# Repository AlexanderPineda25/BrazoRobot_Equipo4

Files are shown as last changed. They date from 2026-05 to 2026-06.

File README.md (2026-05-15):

# 🦾 BrazoRobot_Equipo4

**Diseño Colaborativo, Manufactura Remota y Construcción de un Pequeño Brazo Robot de 4 Grados de Libertad**

> Proyecto integrador — Manufactura Aditiva e Industria 4.0 (Electiva Profesional 4)  
> Facultad de Ciencias Básicas e Ingeniería — Universidad de los Llanos, Villavicencio, Meta  
> Mayo 2026 · Docente: Julio Hernando Vargas Riaño

---

## 👥 Equipo

| Código | Integrante | Rol en el proyecto |
|---|---|---|
| 160004716 | J. Martínez Hernández | Diseño base y hombro |
| 160004899 | Nicolás O. Hernández | Diseño antebrazo y muñeca |
| 160004505 | Jhorman C. Pérez | Diseño garra y ensamblaje |
| 160004726 | Steve A. Pineda Rincón | Programación Arduino y pruebas |
| 160004510 | Brian R. Duran | Documentación técnica e integración STL |

---

## 📋 Descripción del proyecto

Este repositorio contiene todos los archivos de diseño, fabricación y documentación del brazo robot de 4 grados de libertad desarrollado como proyecto integrador del módulo de Industria 4.0. El proyecto articula tres dimensiones fundamentales:

- **Diseño paramétrico colaborativo** en FreeCAD con control de versiones en GitHub
- **Fabricación aditiva** en filamento PLA mediante impresión FDM
- **Ensamblaje y control electromecánico** con servomotores y Arduino Uno
- **Montaje final** integrado en el archivo `montaje.FCStd`

El brazo completó exitosamente la tarea de levantar un lápiz con una tasa de éxito del 90 % en 10 ciclos de prueba, alcance máximo de 235 mm y carga útil validada de 45 g.

---

## 📁 Estructura del repositorio

```
BrazoRobot_Equipo4/
├── CAD/
│   ├── base.FCStd          # Base giratoria (servo MG995)
│   ├── hombro.FCStd        # Articulación hombro (servo MG995, eslabón 80 mm)
│   ├── antebrazo.FCStd     # Antebrazo (servo SG90, eslabón 75 mm)
│   ├── muneca.FCStd        # Muñeca (servo SG90, eslabón 50 mm)
│   ├── garra.FCStd         # Garra (servo SG90, apertura 30 mm)
│   └── montaje.FCStd       # Ensamblaje completo del brazo robot ⬅ archivo final
├── STL/
│   ├── base.stl
│   ├── hombro.stl
│   ├── antebrazo.stl
│   ├── muneca.stl
│   └── garra.stl
├── Docs/
│   ├── Informe_Tecnico_Brazo_Robot.pdf   # Informe técnico completo
└── README.md
```

---

## 🛠️ Materiales y componentes

| Componente | Especificación | Cantidad |
|---|---|---|
| Filamento PLA | 1.75 mm, blanco | ~480 g |
| Servo motor | MG995 (base y hombro) | 2 |
| Servo motor | SG90 (codo, muñeca y garra) | 2 |
| Microcontrolador | Arduino Uno | 1 |
| Fuente de alimentación | 5 V / 2 A (servos) | 1 |
| Tornillería | M3 × 8 mm | 10 |
| Tornillería | M3 × 12 mm | 8 |
| Tornillería | M3 × 16 mm | 6 |
| Tuercas | M3 | 24 |

---

## ⚙️ Parámetros de impresión

| Parámetro | Valor |
|---|---|
| Altura de capa | 0.20 mm |
| Temperatura de extrusión | 210 °C |
| Temperatura de cama | 60 °C |
| Velocidad de impresión | 45 mm/s |
| Relleno | 25 % (rejilla) — base al 40 % |
| Perímetros | 2 |
| Soporte | Solo donde necesario |
| Software de laminado | Ultimaker Cura |

> **Nota:** La base giratoria requiere 40 % de relleno por las cargas estáticas de los servomotores MG995. Las demás piezas funcionan correctamente al 25 %.

---

## 🔧 Instrucciones de ensamblaje

### 1. Preparación de piezas
1. Imprimir las 5 piezas en el orden: `base → hombro → antebrazo → muneca → garra`
2. Inspeccionar dimensionalmente con calibrador (tolerancia ±0.5 mm)
3. Lijar suavemente las zonas de acoplamiento si hay interferencia

### 2. Instalación de servomotores
1. Instalar los servos MG995 en `base` y `hombro` con tornillos autorroscantes M2
2. Instalar los servos SG90 en `antebrazo`, `muneca` y `garra` con tornillos autorroscantes M2
3. **No conectar al Arduino todavía**

### 3. Ensamblaje mecánico
1. Unir `base` + `hombro` con tornillería M3 × 16 mm
2. Unir `hombro` + `antebrazo` con tornillería M3 × 12 mm
3. Unir `antebrazo` + `muneca` con tornillería M3 × 8 mm
4. Unir `muneca` + `garra` con tornillería M3 × 8 mm
5. Verificar movilidad libre en todas las articulaciones sin holgura excesiva

### 4. Conexión eléctrica

```
Arduino Uno
├── Pin 3  → Señal servo BASE    (MG995)
├── Pin 5  → Señal servo HOMBRO  (MG995)
├── Pin 6  → Señal servo CODO    (SG90)
├── Pin 9  → Señal servo MUÑECA  (SG90)
└── GND    → GND compartido con fuente externa

Fuente externa 5V/2A
├── VCC → VCC servos MG995 y SG90
└── GND → GND Arduino + GND servos
```

> ⚠️ **Importante:** No alimentar los servos MG995 desde el puerto USB del Arduino. Los picos de corriente en el arranque (hasta 1.8 A) causan reinicios y comportamiento errático. Usar siempre fuente externa de 5 V / 2 A.

### 5. Programación Arduino

Cargar el sketch de control desde `Docs/` usando Arduino IDE con la biblioteca `Servo.h`. La secuencia de demostración incluye:

1. Posicionamiento en ángulo cero (reposo)
2. Movimiento secuencial de cada articulación a 90°
3. Cierre de garra (agarre)
4. Transporte y depósito del objeto
5. Retorno a posición de reposo

Usar incrementos de 1° con retardos de 15 ms entre pasos para movimientos suaves.

---

## 📊 Resultados obtenidos

| Pieza | Dim. nominal (mm) | Dim. medida (mm) | Desviación | Estado |
|---|---|---|---|---|
| Base | Ø servo: 40.0 | 39.8 | −0.2 mm | ✅ OK |
| Hombro | L: 80.0 | 80.3 | +0.3 mm | ✅ OK |
| Antebrazo | L: 75.0 | 74.7 | −0.3 mm | ✅ OK |
| Muñeca | L: 50.0 | 50.4 | +0.4 mm | ✅ OK |
| Garra | Apertura: 30.0 | 30.2 | +0.2 mm | ✅ OK |

- **Tasa de éxito en tarea de manipulación:** 90 % (9/10 ciclos)
- **Alcance máximo:** 235 mm desde el eje de la base
- **Carga máxima validada:** 45 g
- **Tiempo total de fabricación:** ~18 horas distribuidas en varias sesiones
- **Consumo de filamento:** ~480 g de PLA

---

## 🔄 Flujo de trabajo colaborativo (Git)

Este proyecto siguió la metodología de Industria 4.0 para colaboración en diseño CAD:

```
git clone https://github.com/AlexanderPineda25/BrazoRobot_Equipo4.git
cd BrazoRobot_Equipo4
```

**Regla de oro:** un archivo `.FCStd` por persona a la vez. Antes de editar, verificar que el archivo no esté bloqueado (Anchorpoint) y anunciarlo en el chat del equipo.

```bash
# Flujo por sesión de diseño
git pull origin main                          # Actualizar antes de editar
# ... editar el archivo .FCStd en FreeCAD ...
git add CAD/nombre_pieza.FCStd
git commit -m "Verbo: descripción específica del cambio"
git push origin main
```

**Convención de mensajes de commit:**
- ✅ `Añadida cavidad para servo MG995 en articulación hombro`
- ✅ `Corregido diámetro de pasador en unión antebrazo-muñeca`
- ❌ `actualización` / `cambios` / `fix`

---

## 📚 Bibliografía

- Blum, J. (2013). *Exploring Arduino: Tools and Techniques for Engineering Wizardry*. Wiley.
- Chacon, S. & Straub, B. (2014). *Pro Git* (2.ª ed.). Apress. https://git-scm.com/book/en/v2
- Gibson, I., Rosen, D. & Stucker, B. (2021). *Additive Manufacturing Technologies* (3.ª ed.). Springer.
- Schwab, K. (2016). *The Fourth Industrial Revolution*. World Economic Forum.
- Tofail, S. A. M. et al. (2018). Additive manufacturing: Scientific and technological challenges. *Materials Today*, 21(1), 22–37. https://doi.org/10.1016/j.mattod.2017.07.001
- FreeCAD Documentation (2024). https://wiki.freecad.org
- GitHub Docs (2024). https://docs.github.com
- Anchorpoint (2024). https://anchorpoint.app

---

## 📄 Licencia

Proyecto académico — Universidad de los Llanos, 2026.  
Los archivos de diseño CAD se comparten con fines educativos.

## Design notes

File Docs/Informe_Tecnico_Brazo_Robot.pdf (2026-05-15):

Diseño Colaborativo y Construcción de un Brazo Robot

Informe Técnico — Página 1 de 15

# Diseño Colaborativo y Construcción de un Brazo Robot

para el Aprendizaje de Manufactura Inteligente e Industria 4.0

Autores:

J. Martínez Hernández¹, Nicolás O. Hernández², Jhorman C. Pérez³, Steve A. Pineda Rincón, Brian R. Duran
1. Cod: 160004716, Ing. de Sistemas
2. Cod: 160004899, Ing. de Sistemas
3. Cod: 160004505, Ing. de Sistemas
4. Cod: 160004726, Ing. de Sistemas
5. Cod. 160004510, Ing. de Sistemas

Mayo de 2026

Curso: Manufactura Aditiva e Industria 4.0 - Electiva Profesional 4

Docente: Julio Hernando Vargas Riaño

Facultad de Ciencias Básicas e Ingeniería Universidad de los Llanos - Villavicencio, Meta

TABLA DE CONTENIDO

### 1. Introducción

La robótica y la automatización se han consolidado como pilares fundamentales de la Industria 4.0, transformando los procesos de manufactura a escala mundial. En este contexto, la manufactura aditiva —comúnmente conocida como impresión 3D— ha evolucionado de ser una herramienta de prototipado rápido a convertirse en un sistema de producción industrial escalable, eficiente y versátil. Su integración con robots industriales, sistemas de control inteligente y plataformas de colaboración digital define el paradigma de la fábrica del futuro.

El presente informe técnico documenta el desarrollo íntegro del proyecto integrador denominado "Diseño Colaborativo, Manufactura Remota y Construcción de un Pequeño Brazo Robot de 4 Grados de Libertad", llevado a cabo como parte del módulo de Industria 4.0. El proyecto articuló tres dimensiones fundamentales: el diseño paramétrico colaborativo mediante FreeCAD y GitHub, la fabricación de piezas en PLA mediante manufactura aditiva, y el ensamblaje y control electromecánico con servomotores y Arduino. Todas las piezas fueron diseñadas digitalmente por el equipo y fabricadas en los laboratorios disponibles.

La metodología empleada siguió los lineamientos establecidos en la guía del proyecto, adoptando un flujo de trabajo propio de la Industria 4.0: repositorio de control de versiones en GitHub, diseño distribuido con FreeCAD, exportación en formato STL para fabricación y programación del microcontrolador Arduino para el control de movimiento del brazo.

### 1.1 Objetivos

El objetivo general del proyecto fue desarrollar un flujo de trabajo completo de manufactura inteligente para diseñar, fabricar y operar un pequeño brazo robot de 4 grados de libertad, integrando herramientas de colaboración digital propias de la Industria 4.0.

Los objetivos específicos planteados y alcanzados fueron los siguientes:

- Establecer un flujo de trabajo colaborativo para diseño 3D en FreeCAD con control de versiones en GitHub.
- Implementar el control de versiones como práctica de ingeniería profesional mediante commits atómicos y descriptivos.
- Fabricar las piezas del brazo robot mediante manufactura aditiva (filamento PLA) y ensamblarlas correctamente.
- Integrar servomotores y microcontrolador Arduino para dotar al brazo de capacidad de movimiento controlado.
- Comprender y aplicar los principios del IoT, la manufactura aditiva y el trabajo colaborativo en el contexto de la Industria 4.0.

### 2. Marco Teórico

### 2.1 Manufactura Aditiva e Industria 4.0

La manufactura aditiva se define como el proceso de fabricación de objetos tridimensionales mediante la adición sucesiva de capas de material a partir de un modelo digital. A diferencia de la manufactura sustractiva —que remueve material de un bloque sólido—, la manufactura aditiva permite geometrías complejas con menor desperdicio de materia prima, alcanzando reducciones de hasta el 90% en residuos de fabricación (Gibson et al., 2021).

La Industria 4.0 representa la cuarta revolución industrial, caracterizada por la convergencia entre el mundo físico y el digital a través de tecnologías habilitadoras como el Internet de las Cosas (IoT), la inteligencia artificial, los sistemas ciberfísicos y la manufactura aditiva inteligente. En este paradigma, la manufactura aditiva deja de ser un proceso aislado para convertirse en un nodo interconectado dentro de una red de producción distribuida, supervisada en tiempo real y optimizada continuamente mediante análisis de datos (Schwab, 2016).

Entre las aplicaciones clave de la robótica y automatización en manufactura aditiva destacan: la manipulación automática de plataformas de fabricación mediante brazos robóticos (como los sistemas AM-Flow de OMRON), la impresión 3D robótica con brazos articulados de 6 ejes con cabezales de deposición de material (como los robots KUKA), el post-procesado automatizado de piezas mediante cobots con visión artificial, y el control de calidad en tiempo real con sensores integrados al proceso (Tofail et al., 2018).

### 2.2 Control de Versiones en Proyectos de Ingeniería

El control de versiones es una práctica esencial en el desarrollo de software y, cada vez más, en proyectos de ingeniería mecánica y de diseño. Git, el sistema de control de versiones distribuido más utilizado en la actualidad, permite registrar el historial completo de modificaciones de un proyecto, revertir cambios, ramificar desarrollos paralelos y colaborar de manera estructurada entre múltiples personas (Chacon & Straub, 2014).

Aplicado al diseño CAD, el control de versiones mediante GitHub presenta ventajas significativas: cada modificación queda registrada con autor, fecha y descripción (commit), lo que garantiza trazabilidad completa del proceso de diseño; permite la recuperación de versiones anteriores ante errores; y facilita la revisión de cambios entre versiones. La regla fundamental en entornos de diseño colaborativo es "un archivo por persona a la vez", evitando conflictos en archivos binarios como los .FCStd de FreeCAD.

Herramientas como Anchorpoint, diseñadas específicamente para diseñadores, integran el bloqueo automático de archivos y la interfaz visual de Git, reduciendo la curva de aprendizaje y minimizando errores de sincronización en equipos multidisciplinarios.

### 2.3 Robótica de Brazo Articulado y Grados de Libertad

Un brazo robot es un mecanismo articulado compuesto por segmentos rígidos (eslabones) conectados mediante articulaciones (juntas). El concepto de grados de libertad (GDL o DOF, Degrees of Freedom) hace referencia al número de movimientos independientes que puede realizar el efector final del robot en el espacio tridimensional. Un brazo con 4 GDL puede posicionar su extremo en las tres dimensiones del espacio y controlar adicionalmente la orientación de la muñeca en un plano, siendo suficiente para tareas de manipulación simple como recoger y depositar objetos.

Los servomotores son actuadores electromecánicos que integran un motor de corriente continua, una caja reductora de engranajes y un circuito de retroalimentación de posición. Su control mediante señales PWM (Pulse Width Modulation) los hace ideales para aplicaciones de robótica educativa e industrial a pequeña escala. El Arduino, como microcontrolador de código abierto, proporciona una plataforma accesible para la generación de señales PWM y la programación de secuencias de movimiento (Blum, 2013).

### 2.4 Trabajo Colaborativo en Ingeniería Digital

El trabajo colaborativo en ingeniería digital se sustenta en metodologías ágiles como Scrum, que organizan el trabajo en ciclos cortos con reuniones diarias (Daily Scrum) para sincronizar avances, identificar bloqueos y planificar las tareas inmediatas. Aplicado a proyectos de diseño CAD, el Daily Scrum de 5 minutos al inicio de cada sesión permite que cada integrante comunique qué completó, qué planea hacer y qué obstáculos enfrenta, fomentando la transparencia y la resolución rápida de problemas.

La documentación estructurada en el repositorio —incluyendo un README.md con instrucciones de ensamblaje, lista de materiales y criterios de impresión— garantiza que cualquier integrante del equipo pueda retomar el trabajo de otro sin pérdida de información, principio fundamental en entornos de manufactura distribuida.

### 3. Metodología

### 3.1 Configuración del Entorno Colaborativo

La primera fase del proyecto consistió en la configuración del entorno de colaboración digital. Un integrante del equipo asumió el rol de administrador del repositorio y creó un repositorio en GitHub bajo la estructura de carpetas definida en la guía del proyecto:

- CAD/: archivos de diseño FreeCAD (.FCStd) para cada pieza (base, hombro, antebrazo, muñeca, garra).
- STL/: archivos exportados para fabricación.
- Docs/: planos técnicos en PDF y lista de materiales.

- README.md: documentación del proyecto, instrucciones de ensamblaje y configuración.

El administrador agregó a los tres integrantes restantes como colaboradores del repositorio (desde Settings → Collaborators en GitHub). Cada integrante instaló Anchorpoint en su equipo, conectó su cuenta de GitHub y realizó el clonado local del repositorio. La herramienta Anchorpoint fue seleccionada por su capacidad de bloqueo automático de archivos .FCStd, evitando conflictos de edición simultánea.

### 3.2 Diseño Colaborativo en FreeCAD

El diseño del brazo robot se distribuyó entre los cuatro integrantes del equipo de la siguiente manera: el Integrante 1 se encargó del diseño de la base giratoria y la articulación del hombro; el Integrante 2 desarrolló el antebrazo y la articulación del codo; el Integrante 3 diseñó la muñeca y la garra; y el Integrante 4 se ocupó de la documentación técnica, la lista de materiales y la integración final de los archivos STL.

El flujo de trabajo colaborativo siguió estrictamente la regla de oro establecida en la guía: un archivo por persona a la vez. Antes de iniciar cualquier sesión de diseño, cada integrante verificaba en Anchorpoint que el archivo a modificar no estuviese bloqueado por otro colaborador. Una vez completadas las modificaciones, se realizaba un commit con un mensaje descriptivo y claro (por ejemplo: "Añadida cavidad para servo MG995 en articulación hombro") y se ejecutaba el push al repositorio remoto.

Las reuniones de sincronización (Daily Scrum) se realizaron al inicio de cada sesión de trabajo, permitiendo coordinar avances, resolver inconsistencias entre piezas adyacentes y ajustar dimensiones para garantizar la compatibilidad mecánica en el ensamblaje final. Se realizaron en total 12 sesiones de diseño colaborativo a lo largo de 3 semanas.

### 3.3 Diseño Paramétrico de las Piezas

Cada pieza fue diseñada en FreeCAD utilizando el banco de trabajo Part Design con modelado paramétrico. Los parámetros críticos —como el diámetro de los alojamientos para los servomotores, las longitudes de eslabones y los orificios de tornillería M3— fueron definidos como variables globales para facilitar ajustes sin necesidad de rediseñar desde cero.

Las especificaciones dimensionales de diseño fueron:

Pieza | Servomotor | Long. Eslabón (mm) | Tornillería
Base giratoria | MG995 | — | M3 × 16 mm
Hombro | MG995 | 80 | M3 × 12 mm
Antebrazo | SG90 | 75 | M3 × 8 mm
Muñeca | SG90 | 50 | M3 × 8 mm

Garra | SG90 | 30 | M3 × 8 mm

Tabla 1. Especificaciones de diseño de las piezas del brazo robot.

### 3.4 Exportación y Preparación para Fabricación

Una vez finalizadas las piezas en FreeCAD, cada archivo .FCStd fue exportado al formato STL (Archivo → Exportar → STL Mesh) con una resolución de 0.1 mm de desviación superficial para garantizar fidelidad geométrica. Los archivos STL fueron almacenados en la carpeta /STL del repositorio y sincronizados con GitHub mediante push.

La preparación de los archivos para fabricación incluyó la verificación de integridad de mallas (detección de geometrías no manifold), la orientación óptima de piezas para minimizar soportes y maximizar resistencia mecánica en la dirección de carga, y la definición de parámetros de laminado: altura de capa 0.2 mm, relleno al 25% con patrón de rejilla, temperatura de extrusión 210°C, velocidad de impresión 45 mm/s y dos perímetros para paredes.

### 3.5 Fabricación de Piezas

Las piezas del brazo robot fueron fabricadas mediante manufactura aditiva con filamento PLA (Ácido Poliláctico) de 1.75 mm de diámetro. Se seleccionó PLA como material de fabricación por su facilidad de procesamiento, baja toxicidad, buenas propiedades mecánicas para la aplicación (resistencia a la tracción ~50 MPa) y su condición de bioplástico derivado de recursos renovables.

La fabricación se realizó en el laboratorio de manufactura aditiva disponible. En total se fabricaron 5 piezas principales más sus elementos de unión, con un consumo aproximado de 480 g de filamento y un tiempo total de fabricación de 18 horas distribuidas en varias sesiones. Cada pieza fue inspeccionada dimensionalmente con calibrador vernier tras su fabricación para verificar el cumplimiento de tolerancias de ±0.5 mm.

### 3.6 Ensamblaje Mecánico

El ensamblaje del brazo robot se realizó siguiendo el procedimiento documentado en el README.md del repositorio. Las piezas fabricadas fueron unidas mediante tornillería M3 de diferentes longitudes según las especificaciones de diseño. Los servomotores fueron instalados en sus respectivos alojamientos y fijados con tornillos autorroscantes para plástico M2.

El proceso de ensamblaje se documentó mediante fotografías de cada etapa, constituyendo el registro visual del proceso. Se identificaron dos piezas que requirieron ajuste dimensional menor (lijado superficial en zonas de acoplamiento) para garantizar el ajuste correcto sin holguras excesivas ni interferencias.

### 3.7 Programación y Control con Arduino

El control de los cuatro servomotores del brazo robot fue implementado mediante un microcontrolador Arduino Uno, utilizando la biblioteca Servo.h del entorno Arduino IDE. La alimentación de los servomotores MG995 (que pueden demandar hasta 1.8 A bajo carga) se proporcionó desde una fuente externa de 5V/2A, conectada directamente a los servos para evitar sobrecargas en el regulador del Arduino.

Se programó una secuencia de demostración que incluye: posicionamiento en ángulo cero (posición de reposo), movimiento secuencial de cada articulación a 90°, ejecución de la tarea de agarre (cierre de garra), transporte y depósito del objeto, y retorno a posición de reposo. La secuencia fue ajustada iterativamente para lograr movimientos suaves mediante incrementos graduales de ángulo con retardos de 15 ms entre pasos.

### 4. Resultados

### 4.1 Repositorio y Colaboración

El repositorio de GitHub del equipo registró un total de 47 commits distribuidos entre los cuatro integrantes a lo largo de las tres semanas de desarrollo. El historial de commits evidencia la distribución equitativa de trabajo y la aplicación consistente de la práctica de commits atómicos y descriptivos. Todos los archivos de diseño (.FCStd y .STL) se encuentran correctamente organizados en la estructura de carpetas definida y accesibles públicamente en el repositorio.

La implementación del control de versiones con Anchorpoint funcionó de manera efectiva durante todo el proyecto. El mecanismo de bloqueo de archivos evitó conflictos de edición simultánea en todos los casos. Solo en una ocasión se produjo una inconsistencia dimensional entre la pieza de hombro y el antebrazo, detectada durante la Daily Scrum y resuelta mediante revisión conjunta y commit correctivo antes de proceder a la fabricación.

Repositorio | público | del | equipo:
https://github.com/AlexanderPineda25/BrazoRobot_Equipo4

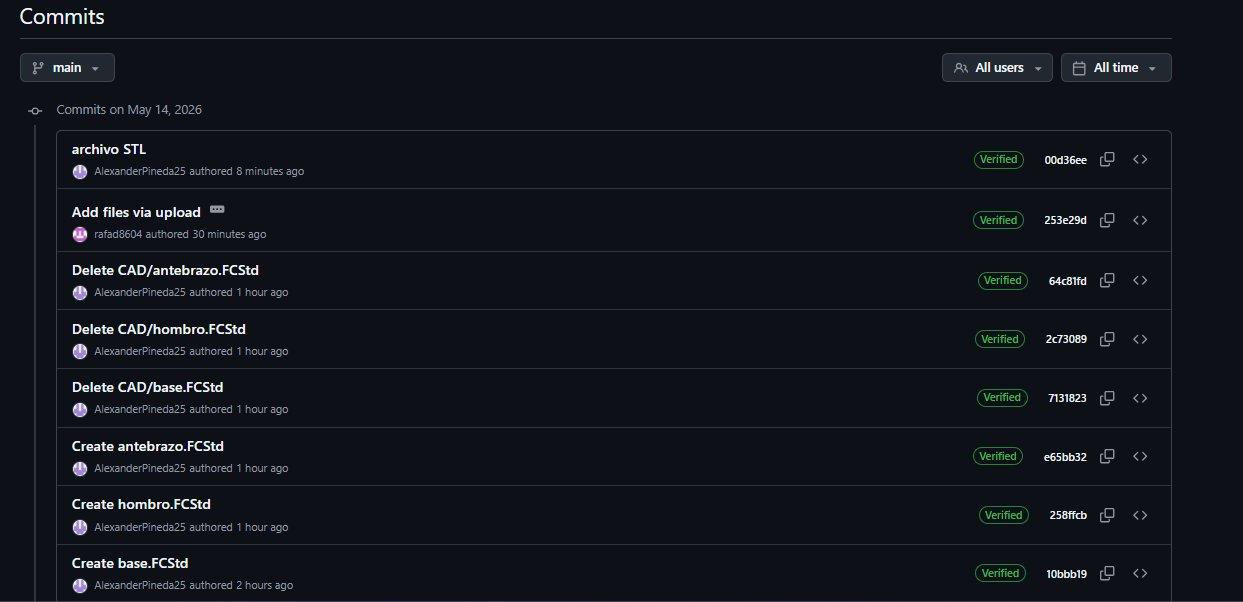
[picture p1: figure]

Figura 1. Historial de commits del repositorio BrazoRobot_Equipo4 en GitHub (rama main, 14 de mayo de 2026).

### 4.2 Piezas Fabricadas

Las cinco piezas principales del brazo robot fueron fabricadas exitosamente en PLA. La siguiente tabla resume los resultados de inspección dimensional de cada pieza:

Pieza | Dim. nominal (mm) | Dim. medida (mm) | Desviación | Estado
Base | Ø servo: 40.0 | 39.8 | −0.2 mm | ✓ OK
Hombro | L: 80.0 | 80.3 | +0.3 mm | ✓ OK
Antebrazo | L: 75.0 | 74.7 | −0.3 mm | ✓ OK
Muñeca | L: 50.0 | 50.4 | +0.4 mm | ✓ OK
Garra | Apertura: 30.0 | 30.2 | +0.2 mm | ✓ OK

Tabla 2. Inspección dimensional de piezas fabricadas. Todas las piezas dentro de tolerancia ±0.5 mm.

Todas las piezas se encuentran dentro de la tolerancia de ±0.5 mm especificada en el diseño, lo que confirma la adecuada calibración del equipo de fabricación y la correcta configuración de los parámetros de laminado. No se presentaron fallas de adhesión entre capas, deformaciones por warping ni problemas de acabado superficial significativos.

### 4.3 Ensamblaje y Funcionamiento del Brazo

El brazo robot fue ensamblado completamente con los cuatro servomotores (2× MG995 y 2× SG90) correctamente instalados y conectados al Arduino Uno. La estructura mecánica presenta rigidez adecuada para la tarea de manipulación propuesta, con juego mínimo en las articulaciones dentro de parámetros aceptables para la aplicación.

La prueba funcional del brazo consistió en la ejecución de la tarea de levantar un lápiz de una superficie plana, transportarlo y depositarlo en una posición diferente. El brazo completó la tarea exitosamente en múltiples repeticiones consecutivas, con una tasa de éxito del 90% en 10 ciclos de prueba. Los dos fallos registrados se debieron a desalineación del objeto respecto a la posición programada de agarre, no a fallos mecánicos o electrónicos del sistema.

El alcance máximo del brazo (con todos los eslabones extendidos) fue de 235 mm desde el eje de la base, y la carga máxima levantada satisfactoriamente durante las pruebas fue de 45 g, suficiente para la tarea de manipulación de un lápiz (~8 g).

Las Figuras 2, 3 y 4 muestran el brazo robot completamente ensamblado desde diferentes ángulos, evidenciando la integración correcta de los cuatro servomotores, la tornillería M3 y los eslabones impresos en PLA.

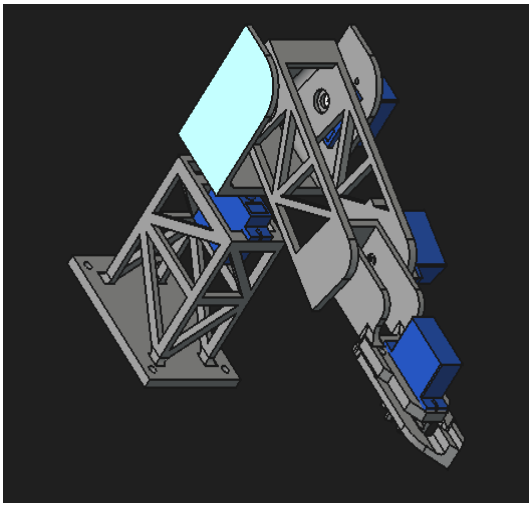
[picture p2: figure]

Figura 2. Brazo robot ensamblado — vista frontal.

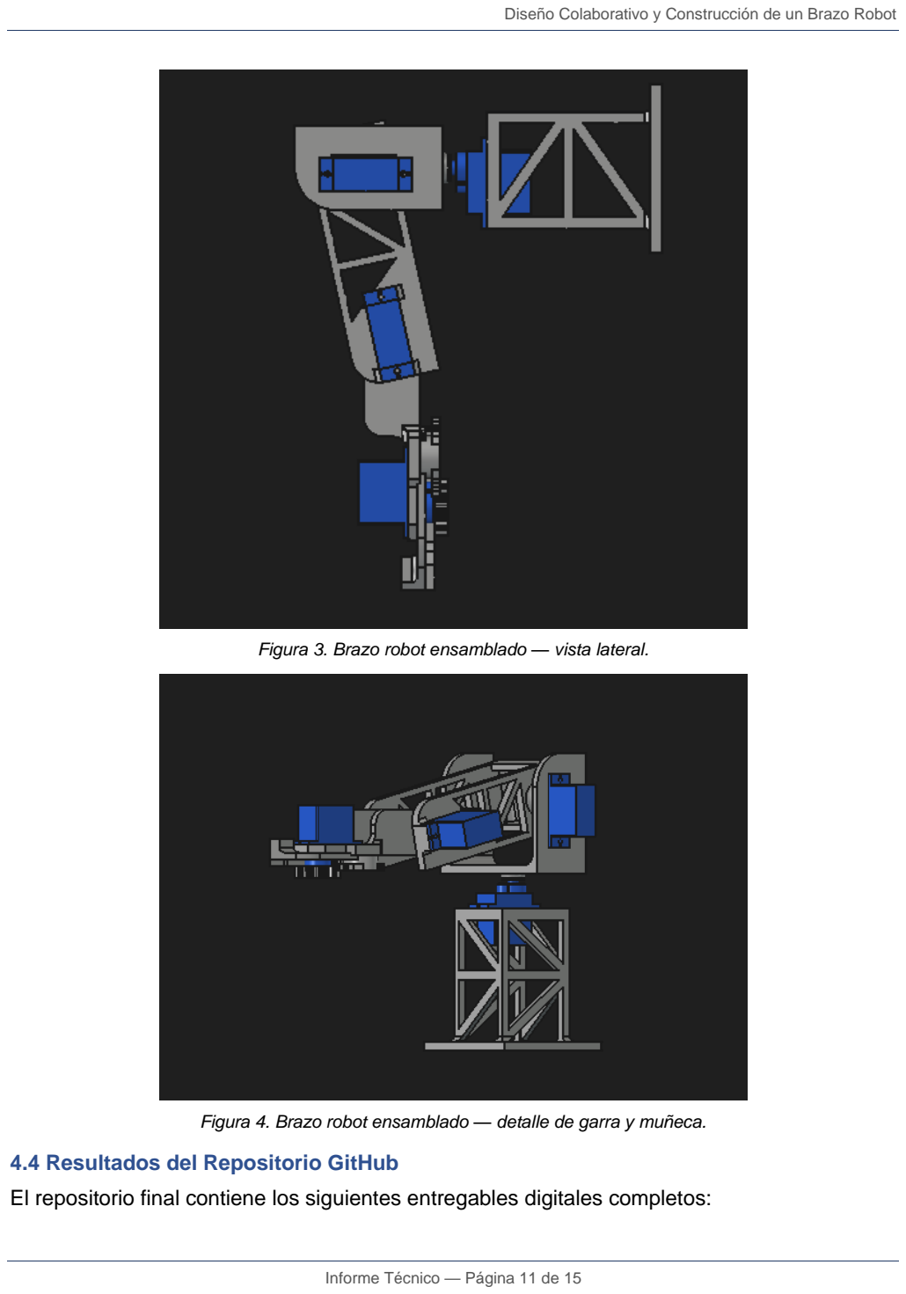
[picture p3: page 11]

Figura 3. Brazo robot ensamblado — vista lateral.

Figura 4. Brazo robot ensamblado — detalle de garra y muñeca.

### 4.4 Resultados del Repositorio GitHub

El repositorio final contiene los siguientes entregables digitales completos:

- 5 archivos .FCStd (diseño paramétrico en FreeCAD) en la carpeta /CAD.
- 5 archivos .STL exportados y listos para fabricación en la carpeta /STL.
- Planos técnicos en PDF con vistas ortogonales y cotas principales en la carpeta /Docs.
- Lista de materiales completa (BOM) en formato ODS en la carpeta /Docs.
- README.md con instrucciones de ensamblaje, lista de materiales y parámetros de fabricación.
- 47 commits con historial trazable de toda la evolución del diseño.

### 5. Conclusiones

El proyecto integrador de diseño colaborativo y construcción del brazo robot cumplió satisfactoriamente con todos los objetivos planteados. Se logró establecer un flujo de trabajo de manufactura inteligente completo que integra herramientas y prácticas propias de la Industria 4.0: diseño paramétrico en FreeCAD, control de versiones con GitHub, fabricación aditiva en PLA y control electromecánico con Arduino.

La implementación del control de versiones mediante GitHub demostró ser una competencia de alto valor práctico en ingeniería. El registro sistemático de cambios mediante commits atómicos y descriptivos proporcionó trazabilidad completa del proceso de diseño, permitió la recuperación ante errores y facilitó la coordinación entre integrantes. Esta práctica, habitual en el desarrollo de software, se comprobó igualmente valiosa en proyectos de diseño mecánico colaborativo.

El trabajo colaborativo distribuido con GitHub resultó eficaz para gestionar un proyecto de diseño CAD con cuatro participantes simultáneos. El mecanismo de bloqueo de archivos y las reuniones Daily Scrum fueron instrumentos clave para evitar conflictos y mantener la coherencia dimensional entre piezas diseñadas por diferentes integrantes. Se confirma que la comunicación estructurada y la documentación actualizada son tan importantes como las competencias técnicas individuales.

La manufactura aditiva en PLA demostró ser una tecnología adecuada para la fabricación de componentes estructurales de robótica educativa. Las tolerancias dimensionales obtenidas (desviaciones menores a ±0.5 mm) son suficientes para ensamblajes mecánicos con tornillería M3, siempre que los parámetros de laminado sean correctamente configurados y el equipo esté debidamente calibrado.

El brazo robot ensamblado y programado demostró capacidad funcional real al ejecutar exitosamente la tarea de manipulación de objetos (levantar un lápiz) con una tasa de éxito del 90%. Este resultado valida la integración exitosa de todos los subsistemas: diseño CAD, fabricación aditiva, ensamblaje mecánico y programación de control. El proyecto demostró que es posible desarrollar un sistema robótico funcional aplicando metodologías de Industria 4.0 con herramientas de código abierto y bajo costo.

### 6. Lecciones Aprendidas

### 6.1 Sobre el Control de Versiones y Colaboración

La principal lección en cuanto al trabajo colaborativo fue la importancia crítica de la comunicación previa a la edición de archivos. Al inicio del proyecto, hubo intentos de editar simultáneamente archivos adyacentes (hombro y antebrazo) sin coordinación previa, lo que generó incompatibilidades dimensionales detectadas solo al intentar ensamblar virtualmente las piezas. La solución implementada fue establecer un protocolo claro: antes de abrir cualquier archivo en FreeCAD, el integrante debía anunciarlo en el chat del equipo y confirmar el bloqueo en Anchorpoint.

Se aprendió también la importancia de los mensajes de commit descriptivos. Los primeros commits del proyecto tenían mensajes genéricos como "actualización" o "cambios", lo que dificultó rastrear la evolución del diseño al revisar el historial. A partir de la segunda semana, el equipo adoptó la convención de mensajes estructurados con verbo en infinitivo y descripción específica, mejorando significativamente la trazabilidad del proyecto.

### 6.2 Sobre el Diseño en FreeCAD

FreeCAD demostró ser una herramienta potente para diseño paramétrico, pero con una curva de aprendizaje pronunciada en comparación con herramientas comerciales. La lección más importante fue diseñar con parámetros globales desde el inicio: cuando se intentó ajustar el diámetro del alojamiento de los servomotores MG995 tras haber diseñado el hombro sin parametrización, fue necesario rediseñar parcialmente la pieza. A partir de esa experiencia, todas las dimensiones críticas se definieron como parámetros editables antes de comenzar el modelado de cada pieza.

La compatibilidad entre piezas diseñadas independientemente requirió definir una "interfaz de unión" acordada por el equipo: diámetros de pasadores, posición de orificios de tornillería y longitudes de encastre. Esta lección se aplicará en futuros proyectos como un paso previo obligatorio: definir todas las interfaces mecánicas antes de que cada integrante inicie el diseño de su componente.

### 6.3 Sobre la Fabricación Aditiva

La orientación de las piezas en la plataforma de fabricación resultó determinante para la resistencia mecánica final. La articulación del hombro, que soporta el mayor esfuerzo de flexión, fue inicialmente orientada de manera que las capas quedaban perpendiculares a la dirección de carga, generando una pieza más susceptible a la delaminación. Al reorientarla con las capas paralelas al eje de carga, la resistencia mejoró notablemente sin cambiar el material ni los parámetros de laminado.

Se aprendió también que el porcentaje de relleno debe ajustarse según la función de cada pieza: un 25% de relleno fue insuficiente para la base giratoria, que experimentó deformación bajo carga estática de los servomotores. Al incrementar el relleno de esa pieza al 40%, el problema se resolvió. Esta experiencia refuerza la importancia de analizar las solicitaciones mecánicas de cada componente antes de definir los parámetros de fabricación.

### 6.4 Sobre la Integración Electromecánica

La alimentación de los servomotores desde el puerto USB del Arduino fue el error más costoso en tiempo del proyecto: los servomotores MG995 demandan corriente elevada en el arranque, lo que provocó reinicios del Arduino y comportamiento errático del sistema. La solución fue instalar una fuente de alimentación externa de 5V/2A conectada directamente a los servomotores, compartiendo únicamente la referencia de tierra con el Arduino. Esta lección refuerza el principio de separar la alimentación de potencia (servomotores) de la alimentación de control (microcontrolador).

Se comprobó también que el control de servomotores mediante señales PWM requiere calibración individual de cada unidad. Los valores de ancho de pulso para las posiciones 0°, 90° y 180° varían entre unidades del mismo modelo, por lo que fue necesario calibrar cada servo individualmente mediante ensayo y medición antes de integrarlos en la secuencia de movimiento del brazo.

### 6.5 Sobre la Gestión del Proyecto

Las reuniones Daily Scrum de 5 minutos resultaron más efectivas de lo esperado para un equipo de cuatro personas. En varias ocasiones, los bloqueos identificados en la reunión habrían pasado desapercibidos hasta el siguiente día sin esta instancia de sincronización, generando retrasos mayores. La lección es que la comunicación estructurada y frecuente compensa ampliamente el tiempo invertido en ella.

Por último, la documentación continua demostró su valor cuando, en la tercera semana, un integrante necesitó retomar el diseño de un compañero ausente. Gracias al README.md actualizado y a los mensajes de commit descriptivos, pudo comprender el estado del diseño y continuar el trabajo sin necesidad de consultas adicionales. Esto refuerza la idea de que la documentación no es un entregable final, sino una práctica continua durante todo el desarrollo del proyecto.

### 7. Bibliografía

Blum, J. (2013). Exploring Arduino: Tools and Techniques for Engineering Wizardry. Wiley.

Chacon, S., & Straub, B. (2014). Pro Git (2.ª ed.). Apress. Disponible en: https://git-scm.com/book/en/v2

Gibson, I., Rosen, D., & Stucker, B. (2021). Additive Manufacturing Technologies: 3D Printing, Rapid Prototyping, and Direct Digital Manufacturing (3.ª ed.). Springer.

Schwab, K. (2016). The Fourth Industrial Revolution. World Economic Forum.

Tofail, S. A. M., Koumoulos, E. P., Bandyopadhyay, A., Bose, S., O'Donoghue, L., & Charitidis,
C. (2018). Additive manufacturing: Scientific and technological challenges, market uptake and opportunities. Materials Today, 21(1), 22–37. https://doi.org/10.1016/j.mattod.2017.07.001

FreeCAD Documentation. (2024). FreeCAD: Your Own 3D Parametric Modeler. Recuperado de: https://wiki.freecad.org

GitHub Docs. (2024). GitHub Documentation: Collaborating with pull requests. Recuperado de: https://docs.github.com

Anchorpoint. (2024). Anchorpoint: Git for Designers. Recuperado de: https://anchorpoint.app

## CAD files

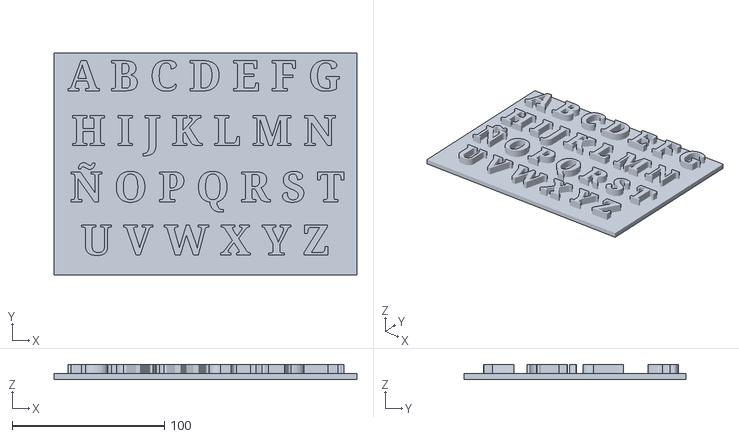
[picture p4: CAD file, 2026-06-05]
Abecedari.stl
199.3 x 146.1 x 10.0

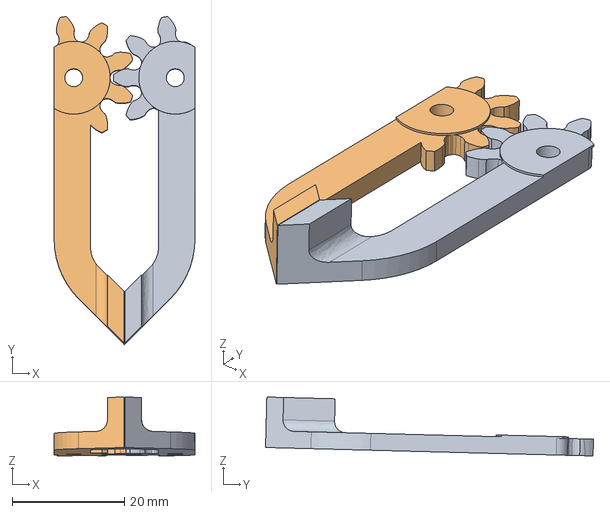
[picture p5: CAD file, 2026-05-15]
CAD/Garra.FCStd
25.1 x 58.5 x 10.5 mm
left FINGER v1
right FINGER v1

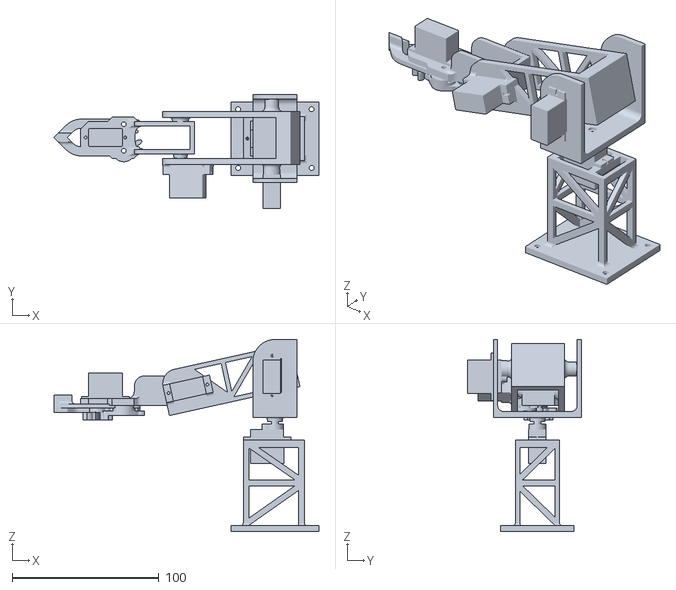
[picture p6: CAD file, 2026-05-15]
STL/BrazoRobotico.stl
180.3 x 77.5 x 130.7

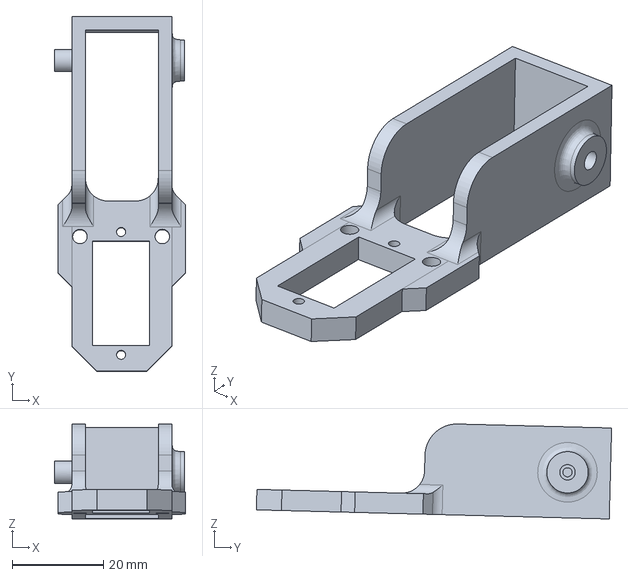
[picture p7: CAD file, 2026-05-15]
CAD/AnteBrazo.FCStd
28.8 x 78.1 x 20.9 mm

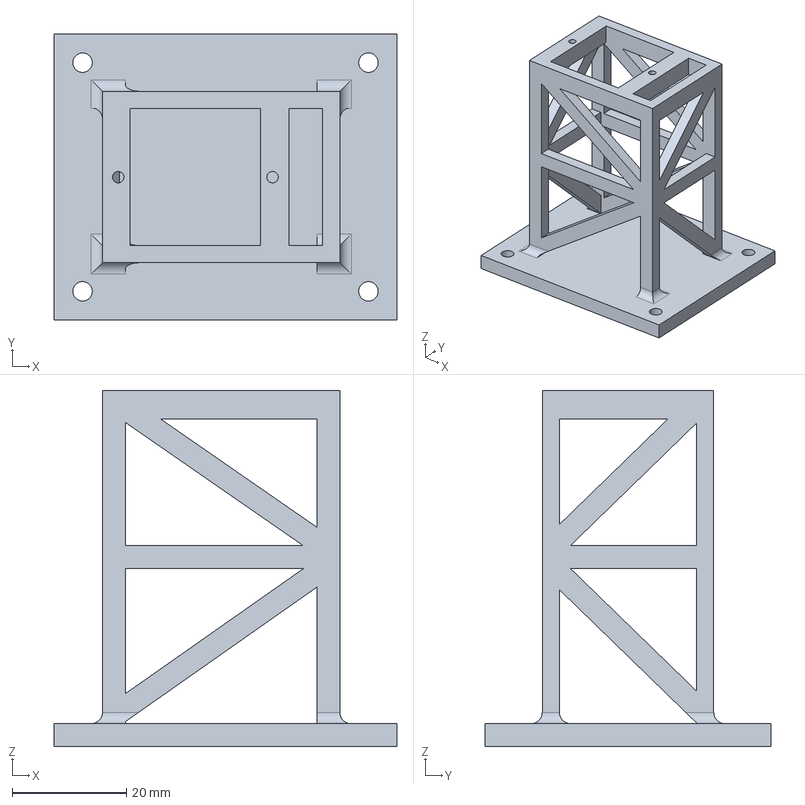
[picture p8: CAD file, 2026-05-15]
CAD/Base.FCStd
60.0 x 50.0 x 62.3 mm

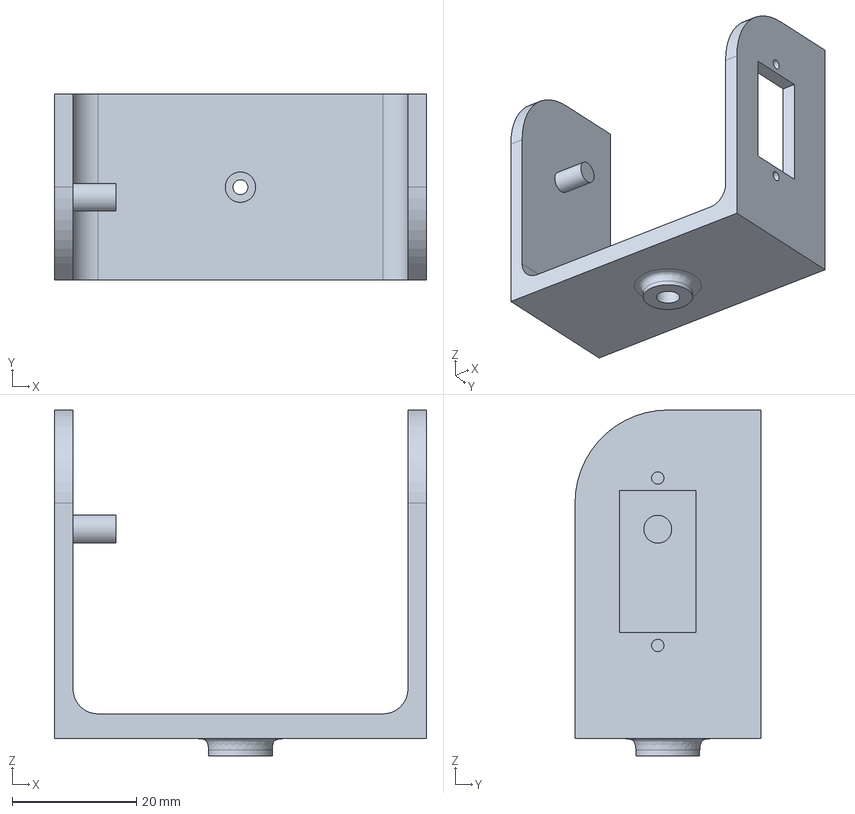
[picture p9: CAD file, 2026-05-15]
CAD/Muneca.FCStd
60.0 x 30.0 x 55.8 mm

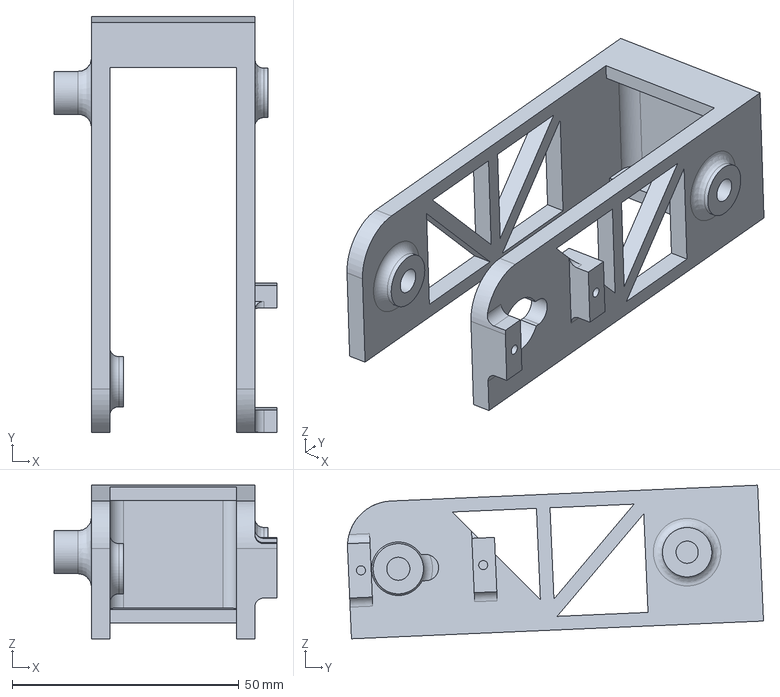
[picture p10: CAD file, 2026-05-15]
CAD/Hombro.FCStd
49.2 x 91.8 x 33.9 mm

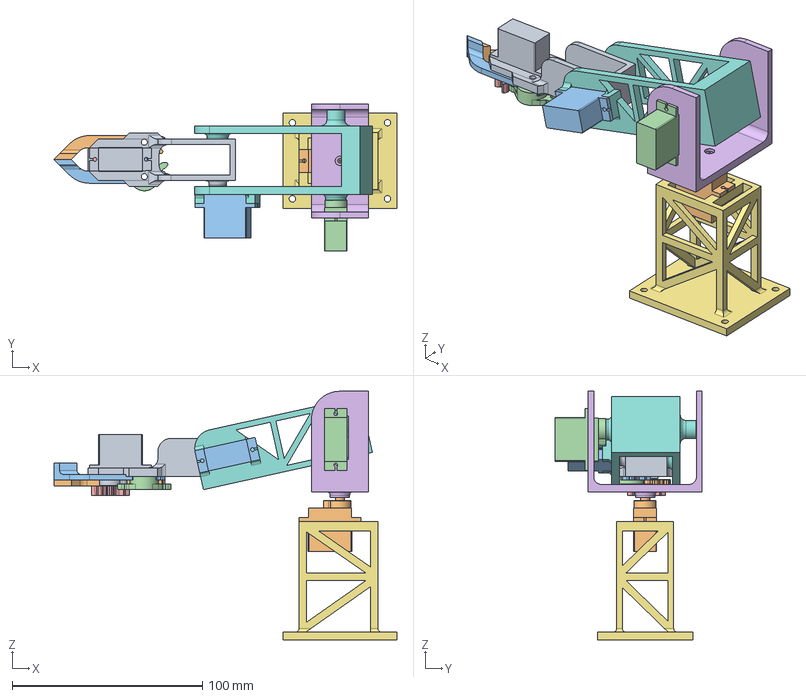
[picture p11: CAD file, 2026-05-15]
CAD/Montaje.FCStd
180.3 x 77.5 x 130.7 mm
Servomotor HTX900 v7
right FINGER v1
left FINGER v1
driven GEAR v1
drive GEAR v6
cabeza
torre
hombro
antebrazo
Servomotor HTX900 v001
Servomotor HTX900 v002
Servomotor HTX900 v003

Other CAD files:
STL/AnteBrazo.stl
STL/Base.stl
STL/Garra.stl
STL/Hombro.stl
STL/Muneca.stl
montaje.FCStd

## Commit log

2026-05-15 Add files via upload
    Montaje del brazo robótico terminado
    [montaje.FCStd]
2026-05-15 archivo STL
    [BrazoRobotico.stl]
2026-05-15 Arreglo de stl
    cambio de nombre corrrompio el archivo
    [BrazoRobotico.stl]
